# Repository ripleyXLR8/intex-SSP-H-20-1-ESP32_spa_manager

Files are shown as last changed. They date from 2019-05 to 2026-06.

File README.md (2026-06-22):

# WORK IN PROGRESS

# Intex SSP-H-20-1 ESP32 Spa Manager

**WARNING 1 : The circuit in this project uses main voltage (220-240 Volt AC in western Europe). This can be deadly if not handled properly! You can easily hurt yourself as well. Build this circuit at your own risk.**

**WARNING 2 : Never ever ever power this circuit directly without a GFCI outlet (differential circuit breaker). Remember this wircuit will be used in a wet environnement. If you don't understand this, please watch this video https://www.youtube.com/watch?v=SHGo-52wCDc&t=63s and get some electrical knowledge about ground protection.**

**WARNING 3 : This project is still a work in progress, this page is a kind of building log, I haven't finish the board building and installation for the moment. Watch the issues page to see what is working and what is not.**

This project aims to build a replacement for the motherboard of the Intex SSP-20 Spa (it may work with other Intex spa and could be used to build a spa from scratch, but this is not the purpose of this page). My goal was to be able to control the spa remotely and integrate it in my domotic system. The board communicates over the MQTT protocol and publishes Home Assistant MQTT auto-discovery messages, so it integrates out of the box with Home Assistant (and works with any MQTT-based system such as Jeedom https://www.jeedom.com/). The second goal of this project is to improve the reliability of this spa and specificaly to solve a random E95 or E9X error problem. My spa was still under waranty when i started this project so I tried to be as stealth as possible.

## 1) Intex motherboard reverse engineering
Below the annotate picture of the motherboard with my understanding of its working principle. Since the card is labeled, everything is pretty straight forward except the descaler system and the pump system (the upper terminal barrier connector on the board).

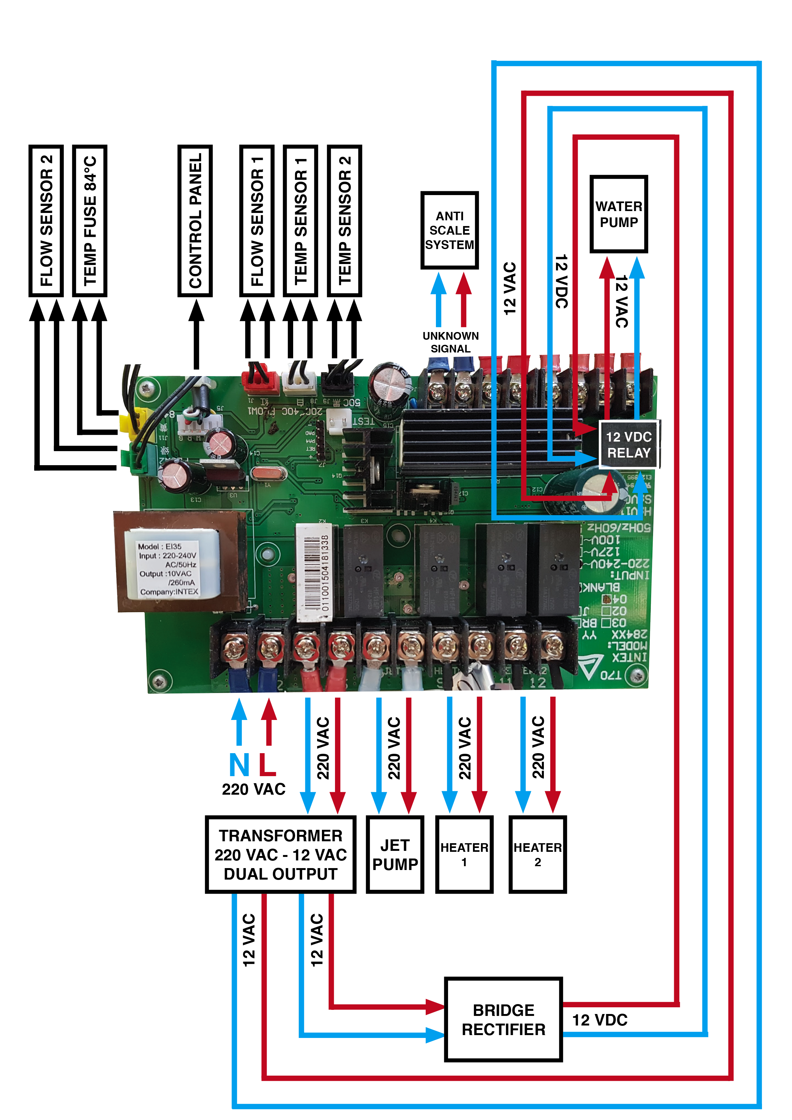
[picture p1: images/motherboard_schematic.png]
Motherboard schematic


### a) Sensors
There are 5 sensors connected to the board, 2 temperature sensors (black and white connectors), 2 flow sensors (red and green connectors) and 1 temperature fuse (yellow connector). They are all connected with a 3 pins JST like connector (it looks like a JST XH 3P but the JST XH 3P doesn't have a lock mecanism).

#### Temperature sensors
Both temperature sensors are negative temperature coefficient (NTC) thermistore, it means that the resistance of the thermistore decreases with an increase in temperature.

- The temperature sensor 1 is installed at the intake of the water pump so it reads the water temperature and it is use to regulate the water temperature from 20°C to 40°C.

- The temperature sensor 2 is installed in the core of  heating elements and its function is to detect overheating over 50°C and shut down the heating if necessary.

Since I'm reading a resistance value and not a temperature, I need to do some calibration (i.e. find a relation between the resistance I'm measuring and the temperature). To measure the real temperature of the water in the spa I connected a DS18B20 thermal sensor in place of the LCD panel. Then I have recorded the temperature of the water and the resistance of both integrated temperature probe of the spa during the heating process of the spa from 18°C to 40°C. The resut once smoothed is the curve presented below. (smoothing is mandatory since the ADC of the ESP32 is pretty noisy...)

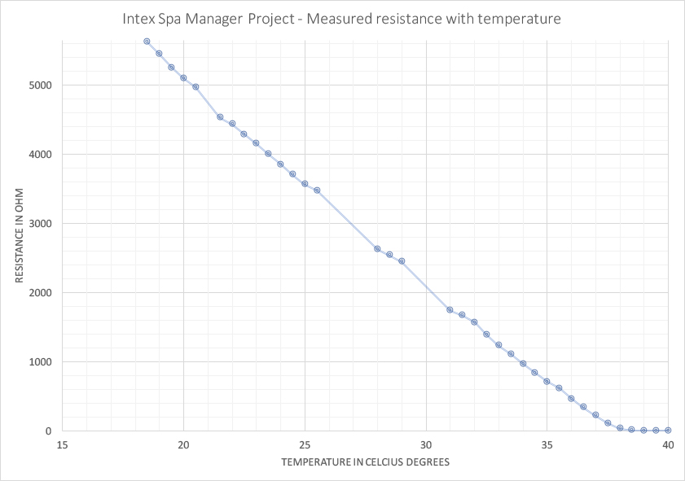
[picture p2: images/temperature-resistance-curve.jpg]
Temperature resistance curve


I first tried to use the Steinhart-Hart equation https://fr.wikipedia.org/wiki/Relation_de_Steinhart-Hart but O did not get good results using this equation, especialy from 34 to 38 degrees.

Since I'm observing that the curve is pretty linear from 18 to 38 degrees, and that the value of the resistance is 0 for 40°C, I tried a linear regression. The result is pretty decent with a R=0,9926.

The equation is T = -276,38*R + 10513

You can also try a logarithmic regression an get the following equation : T = -7750*Ln(R) + 28589 

#### Temperature fuse
One temperature fuse is installed just below heating elements. I cannot test the triggering temperature but it seems that in normal condition the fuse let the current pass and if the temperature goes over 84°C then the fuse burn and the current stop passing and shut down the heating.

#### Flow sensors
Both flow sensors let the current pass only if flow is detected, they ensure that no heating is activated if there is no flow detected in the system.

### b) Power supply, relays and other parts
All the power cable (input and outputs) are connected by a barrier terminal block. We will use the same connector on our board because we don't want to alter the power cable and change their connector.

#### Heating elements
There is two heating element in the spa for a total power of 2000 Watts. They are directly powered by a relay allowing 220VAC to pass trough the heating element.
Please note that in normal condition :
- The water pump is always powered when heating. Any flow interruption signaled by the flow sensor result in an error and the heating stops.
- When you push the heating button the heating doesn't start immediately, the water pump starts and then a couple seconds after the heater 1 is powered then a couple seconds later the heater 2 starts.
- The heater 2 is shut-down if the jet pump is activated.

#### Jet pump
The jet pump is directly powered by a relay allowing 220VAC to pass trough the pump and pumping air into the Spa.

#### Water pump
The water pump is powered by 12VAC but before that a relay allows 220VAC to flow through a dual output 12VAC transformer (see the drawing above). The first output is send to a closed relay and the second output of the transformer goes into a full bridge rectifier producing 12VDC send to activate the relay and let the 12VAC flow into the water pump. It seems that the only goal of this system is to allow the descaling system to start at the same time as the pump (see below the descaling system). On this version on the board we will not implement the descaling system (maybe on the next version) so we will power the pump directly from the output transformer. (connection of A and B wires to C and D wires)

#### Control panel
I will replace the control panel with an external control box connected through the enclosure of the spa with an IP68 SP21-12 connector. (available here : https://www.amazon.com/gp/product/B071R6RSN6/ref=ppx_yo_dt_b_asin_title_o00_s00?ie=UTF8&psc=1)

#### Descaler system
It seems that this spa is equiped by a magnetic descaling system. Here is the wikipedia page on this technology (https://en.wikipedia.org/wiki/Magnetic_water_treatment). I cannot find the type of signal send to this device, it seems that the signal is AC with a modulation of amplitude. I will maybe investigate it later... so this function has not been implemented on the replacement board.

## 2) Designing the replacement board
### a) Working principle
An ESP32 (DevKitc) is the heart of the system. It allows us to connect : 
- 2 temperature sensors on 2 analog inputs,
- 2 flow sensors on 2 digital inputs,
- 1 temperature fuse on 1 digital input,
- 5 buttons on 5 digital input (PUMP, HEATING, JET, +, -),
- 1 LCD display on 2 digital inputs (I2C protocol),
- 4 power relays on 4 digital inputs.

Relays, LCD, temperature sensors, flow sensors, and buttons will not be powered from the 5 Volt pin of the arduino, we will use directly the 5 Volt DC power supply to power them directly.

The integrated wifi chip also allow us to connect to the wifi and the MQTT server to send and receive data.

### b) Electrical drawing
I used Eagle 8.2.2 to design the replacement board, below is the electrical drawing. The eagle files will be available soon.

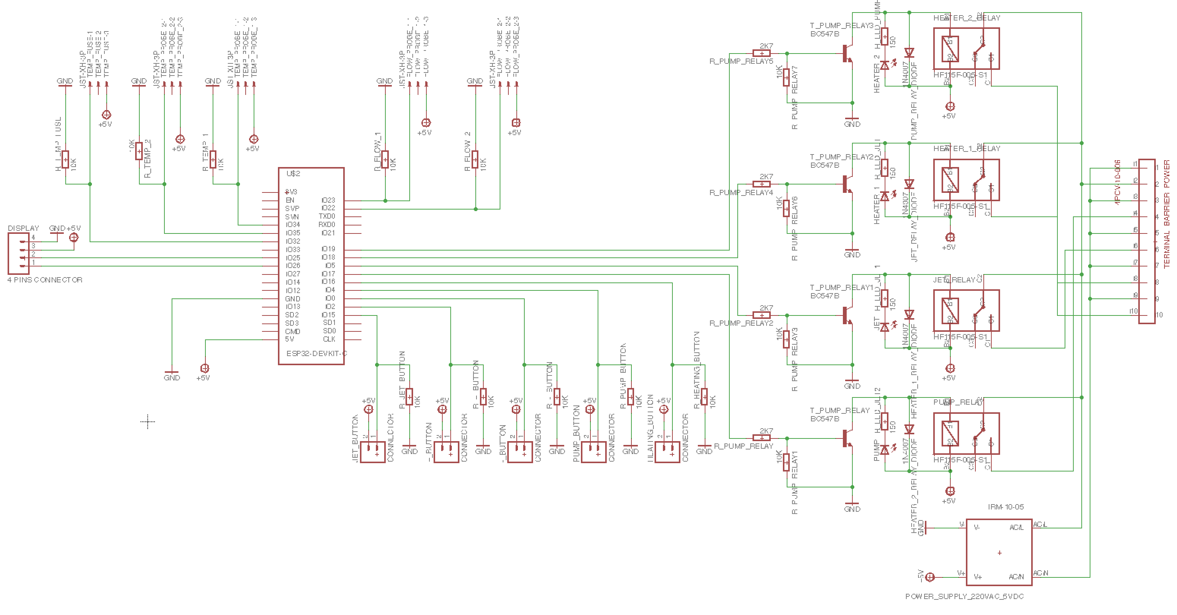
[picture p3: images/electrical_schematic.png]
Electrical schematic


### c) Board schematic
I wanted the board to be easily produce at home by anybody so I choose to use a single side PCB with plated-trhough holes (PTH) components. SMD component will be a also good choice, but I know that occasionnal welder are more at ease with PTH components. The drilling size is 0.8mm, the width of the electrical tracks is 16mil (0.40mm) and the clearance is 10mil (0.25mm), theses parameters allows you to produce the board using the toner transfer method (this method requires very few tools).

Relays are integrated on the board to be integrated more easily in the original enclosure.

The original motherboard dimension are 10.5 cm x 17 cm, mounting hole are 5mm wide and are placed 4.5mm from the edge of the board. The PCB will be mounted using the same mounting screw used by the original motherboard (but I don't think I will be using the center plastic lock).

The power tracks (tracks going to relays) will carry a lot of current. The total power of the Spa announced by Intex is 2200 watts. I have made some measurement on the original board to see how much current is use by each component :

- Heater 1 : 6.70A (Peak at startup) / 3.70A (Cruise) @ 220 Volt AC
- Heater 2 : 7.00A (Peak at startup) / 4.00A (Cruise) @ 220 Volt AC
- Water pump : 0.16A @ 12 Volt AC (This measure include also de descaler) 
- Air pump : 5.50A (Peak at startup) / 3.60A (Cruise) @ 220 Volt AC

As we can see, if everything is running at the same time the spa can draw a total of 11.46A with a peak at startup of 19,36A which is a lot. In the original board there is some rules to avoid the spa to reach this high current drawing :

- Heater 1 and 2 have a 20 seconds startup delay between each other.
- Air pump and heater 2 can't run at the same time.

We will implement the same rules to our board so the maximum current draw will be around 8A with a peak around 11A when starting the heater or the pump. (Which is about what is announced by Intex around 2400 Watts). By dimension the track width for 10A, 2oz/ft copper, an ambiant temperature of 25°C and a maximum temperature elevation of 5 degrees, we find that we need a 2,36 mm (93mil) track width.

### d) Board production
Board schematic has been sent to PCBway a chinese PCB prototyping company. https://www.pcbway.com/. They can even populate your board with the component if you want them to do it.

The list of component with links to buy them is provided below :

## 5) How to configure and install the new control board
### a) Uploading the code and first-boot configuration
Open the lastest `*.ino` file within the Arduino IDE. You no longer need to edit WiFi or MQTT credentials in the code — they are configured at runtime through a captive WiFi portal (WiFiManager) and saved in the ESP32 flash memory.

The feature flags at the top of the sketch are enabled by default and normally don't need to be changed :
`const bool wifi_enable = true;`
`const bool mqtt_enable = true;`
`const bool ota_enable = true;`  // WiFi OTA: lets you upload future updates over the air, without opening the case

Place your ESP32 on a breadboard, select the ESP32 board, set the baudrate to 115200 and upload the code. Once the upload is finished, press the reset button of the board.

On first boot (or whenever it cannot reach a known WiFi network) the board starts a WiFi access point named **`Spa-Intex-Config`**. Connect to it with a phone or computer and a captive portal opens where you set :
- your WiFi network and password,
- the MQTT server address and port (default `1883`),
- the MQTT username and password (leave empty if your broker has no authentication),
- the **OTA password** that protects over-the-air firmware updates.

These settings are stored permanently in the ESP32 flash. To erase the saved WiFi configuration and force the portal to reopen, **hold the BOOT button (GPIO 0)** while resetting the board.

⚠️ **Set the OTA password.** If you leave it empty, anyone on your network can flash arbitrary firmware to a board that switches 2 kW of mains heaters. The board logs a red warning at start-up while the OTA password is unset.

If the board cannot connect to WiFi within the portal timeout (180 s) it falls back to an **offline mode** : the local heating, filtration and jet logic keeps running, but no remote control is available.

### b) Checking the board connection
Open the serial port monitor of the Arduino IDE and set the baudrate to 115200. You should see the start-up sequence and the IP of your board on the WiFi network. Once connected, you can also open a **Telnet** session to that IP (port 23) to watch the live dashboard remotely — it prints the temperature, target, thermostat/filtration/jet/heater states and the anti-short-cycle timer every few seconds.

If you have any error message during the start-up you should check your configuration in the WiFi portal.

### c) Controlling the spa over MQTT
The board uses MQTT only (the previous HTTP/REST interface has been removed). It publishes its full state as a JSON payload to the **`spa_intex/info`** topic, for example :

`{"flow_1":true,"flow_2":true,"temp_1":21.3,"temp_2":21.8,"target":35.0,"heartbeat":65065,"thermostat":false,"filtration":false,"heater":false,"jet":true,"fuse":true,"bypass_flow":false,"bypass_fuse":false}`

In that payload `fuse:true` means the thermal fuse reads intact (safe to heat) and `flow_1/flow_2:true` mean water flow is detected.

Command topics (publish `1` or `0`, or a number for the target) :
- `spa_intex/target` -> set the target temperature (°C, capped at 39 °C).
- `spa_intex/thermostat` -> enable/disable the temperature regulation (enabling it also turns filtration on). Accepts `1`/`0` or `heat`/`off`.
- `spa_intex/filtration` -> enable/disable the filtration (water pump).
- `spa_intex/jet` -> enable/disable the jet (air pump / bubbles).
- `spa_intex/reset` -> publish `1` to reboot the board after a 10 s delay.
- `spa_intex/bypass_flow` -> override the water-flow interlock (see safety section below).
- `spa_intex/bypass_fuse` -> override the thermal-fuse interlock (see safety section below).

On every successful MQTT connection the board also publishes **Home Assistant MQTT auto-discovery** messages (under the `homeassistant/...` topics), so the device appears automatically as "Spa Intex" in Home Assistant — no manual entity configuration required. The thermostat is exposed as a single **`climate`** entity (current temperature, target slider, off/heat mode and a heating/idle indicator); the filtration and jet are switches, and the two interlock overrides are switches in the *Configuration* section. (The thermostat + setpoint were previously two separate switch/number entities — these are now removed in favour of the climate card.)

### d) Safety interlocks and current limiting
The heating logic enforces several hardware-protection rules. The heater stays off unless **all** of these hold:
- the thermostat is enabled and the water is below target (with a ±1 °C hysteresis band),
- **water flow is detected** on both flow sensors (`flow_1` and `flow_2`),
- the **thermal fuse reads intact** (`fuse`),
- the water temperature is below the 39 °C safety ceiling,
- the 15-minute anti-short-cycle timer allows the change (bypassed once on the first cycle).

To limit the inrush current (the original board draws up to ~19 A peak with everything starting at once), the firmware reproduces the factory rules: **heater 2 starts only ~20 s after heater 1**, and **heater 2 never runs at the same time as the jet/air pump** (turning the jet on temporarily drops heater 2). The live dashboard (serial / Telnet) shows which interlock is currently blocking the heater.

**Input polarity must match your board.** The active levels are defined at the top of the sketch:
`#define FLOW_ACTIVE_LEVEL HIGH` (level read when water flows) and `#define FUSE_OK_LEVEL HIGH` (level read when the fuse is intact). They default to *high = active*; if your wiring is inverted, flip these two `#define`s, otherwise the interlocks will read backwards. A disconnected flow or fuse input is treated as "no flow / fuse tripped" and **blocks heating** (fail-safe) — so the thermal-fuse (yellow) and flow connectors must be wired and working for the spa to heat.

#### Bypassing a broken sensor
If a flow sensor or the thermal fuse is faulty and you knowingly want to keep heating until you can replace it, two MQTT overrides let you bypass the interlock without touching the code:
- `spa_intex/bypass_flow` -> publish `1` to ignore the water-flow check, `0` to restore it.
- `spa_intex/bypass_fuse` -> publish `1` to ignore the thermal-fuse check, `0` to restore it.

Both are exposed as switches in the **Configuration** section of the Home Assistant device ("Spa Bypass Debit" / "Spa Bypass Fusible"), reported in the `info` payload (`bypass_flow` / `bypass_fuse`), and shown on the serial/Telnet dashboard (`Securites : Fusible [ACTIVE/CONTOURNEE] | Debit [...]`) with a red warning when engaged.

⚠️ **A bypass resets to OFF on every reboot/power-cycle** — it is deliberately not persisted, so cycling power always restores full safety. Bypassing the thermal fuse removes overheat protection; the only remaining backstop is the 39 °C software ceiling on the regulation sensor. Use these overrides only as a temporary measure and never leave the spa unattended while a bypass is active.

### e) Removing the old control board
First, it is very important to DISCONNECT THE POWER CABLE of the Spa. Remove the four screws securing the spa cover and remove it. Then locate the cover of the control board, remove all the screws and remove the cover. On the control board remove all cable from the lower and upper terminal, from the sensors and from the control panel, then remove the four screws securing the board and remove it.

### f) Installation of the new control board
Remove the central plastic pin in order to install the new board into the enclosure and then install the new board using the 4 screws from the old board. Then connect the old cables on the new board. Here is a quick connection guide based on the color of my board (double check it with you board before powering up the spa) :

- Red connector -> Flow 1 connector
- Green connector -> Flow 2 connector
- White connector ->  Temperature 2 connector
- Black connector ->  Temperature 1 connector
- Yellow connector -> DO NOT CONNECT (it doesn't work currently)
- Connector 1 -> N terminal
- Connector 2 -> L terminal
- Connector 5 -> N of the pump terminal
- Connector 6 -> L of the pump terminal
- Connector 7 -> N of the jet terminal
- Connector 8 -> L of the jet terminal
- Connector 9 -> N of the heater 1 terminal
- Connector 10 -> L of the heater 1 terminal
- Connector 11 -> N of the heater 2 terminal
- Connector 12 -> L of the heater 2 terminal

Then you have to connect together some wires from the upper terminal and isolate all non connected wires before powering up the spa.
- Cable A must be connected with cable C
- Cable B must be connected with cable D

You should get something like that :
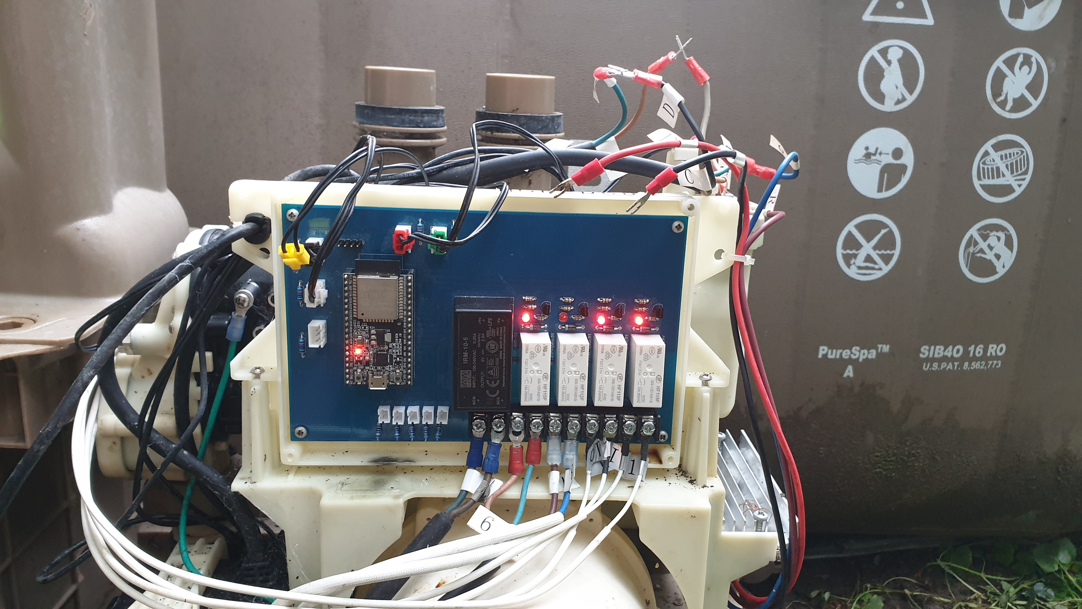
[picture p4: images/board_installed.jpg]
Board installed


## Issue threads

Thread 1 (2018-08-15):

Project Update

olivercastle, 2018-08-15:
Hey Richard,

Great project you have started here. I'm also looking to do something similar to my Intex spa. Final product would ideally be able to control the spa remotely maybe using ifttt or something of the like.

Are you still working on this? Have you made any progress since your last commit?

Thanks.

ripleyXLR8, 2018-08-16:
Hello Oliver,

Unfortunately I had two major problems in this project. My computer has
been stolen with all the code i had written and the first PCB i ordered
online had some major design flaw. So the project has been kinda stopped.

I have designed a new version of the PCB but it must be checked before
sending it to production. I can send it to you soon.

Best regards

Richard

Le mer. 15 août 2018 à 06:31, Oliver Castle <notifications@github.com> a
écrit :

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

olivercastle, 2018-08-20:
Hi Richard,

Sorry to hear about your computer.

Yes would be really interested in seeing what you come up with.

Oliver

ripleyXLR8, 2018-08-22:
This is the last version of the board I designed. (eagle files)

There is still some things to check :

1) I'm using a lot of input from the ESP32, i did not check if they can be
used simultaneously (i had some surprise on previous project with the ESP
32)
2) Value for component must be checked.
3) I did not reverse the descaling system.

Thank you for your mail.

Actually you gave me some strenght to get back to work on this project.

I will try to finish  the board before the end of august.

Best regards

Richard

2018-08-20 19:34 GMT-04:00 Oliver Castle <notifications@github.com>:

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

--
*Richard Perez*
*Tel : 06 25 68 70 54*

*Importateur Exclusif France*

*  & *

Listwa, 2018-09-18:
Hi,
I am following. Would like to also remotely control the Intex Spa.  I use my Spa at a vacation home on weekends and lower  the temp when i leave.  I would love to simply be able to raise the temp to 104,  a day before i arrive.  I was looking for a way just to tap a raspberry Pi or an arduino into the control panel to control the temp.  Any  ideas are welcome.

Regards
Les

tinwhisker, 2019-01-31:
Hi guys,

I have a pet-project for a similar goal to Richards, but reading the bad news, I thought I'd reach out if anyone was interested? Even if it's a stop-gap.

Personally it was on hiatus for a while, but decided to pick it back up. But being lazy, I thought I'd check GitHub first and found this project.

It takes a different approach, using the display lines for state/control, as I wanted as minimal modification as possible. (Like Richard, mine was in warranty when I started).

Four wires - power, data and clock. An ESP8266 sits in parallel to the display board.
Just revisiting write-back stability, but I'll throw it up on GitHub if anyone wants a peek.

I'm half tempted to move it to where the main board lives to gain access to a reset pin, so I can clear errors too.

Listwa, 2019-01-31:
Yes, please share. Pictures also of where  and how you connected to the
display.

Would love to remotely adjust the Spa,

Les

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

olivercastle, 2019-02-01:
@tinwhisker Yes, if we can combine efforts that would be awesome too.
I also had the thought of an Arduino running in tandem with the existing board so we're not removing the current functionality only extending it.

@ripleyXLR8 Do you have any thoughts on that?

Personally, my main goal is to be able to turn my system on/off / adjust temperatures during certain times of the day (low electrical cost times for example).

Thanks!

Listwa, 2019-02-01:
Hi Oliver,

An Arduino or Raspberry Pi would be the way to go and yes running in
tandem.  One of the problems I am dealing with is that after a power outage
( I get many), the unit has to be manually turned back on and temp
readjusted.  Its located at a Vacation home, so I keep  the temp low and
raise it when I get there and have to wait  and wait for it to come to
temp.    I have played with a Raspberry pi with a water proof temp sensor
to tell me what the temp is remotely, but that is as far as my technical
capabilities .  Never bothered to take the control unit apart and hack into
it.

Les

On Fri, Feb 1, 2019 at 9:13 AM Oliver Castle <notifications@github.com>
wrote:

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

tinwhisker, 2019-02-01:
The Pi might be able to do it if you can have decent control over the SPI lines.
I don't think it's interrupts would be fast enough.
You could definitely use a cheap arduino, (especially a Leonardo or Teensy) to do the grunt work, though the ESP keeps cost to a minimum.

The ESP on my first go wasn't so happy with SPI abuse, but may try again if I can confirm it's SPI interrupt is separate. Bit-banging is quite CPU intensive, but doesn't need realtime reading - even every 500ms is overkill, just syncing to the data line adds time.

Write-back is clever, but fiddly as, from what I remember, the spa clocks a bit through the two 595's, checking the data line for state change (where a button is pulling it up/down), then clocks again.
Get the write-back wrong and the panel locks out.

I'll try get a good snapshot of the data line again tomorrow if I can't find my original.
Tonight I'm using the tub, so not allowed to tinker!

tinwhisker, 2019-02-01:
Does anyone have a picture of the back of the main board? I can only find component side images.

Listwa, 2019-02-09:
Hi,

I am going to go for now in a different direction.  As I would like to keep the temp down for weeks at a time, since I only occasionally use the Spa , but rapidly warm it up and not wait 24 hours.  I am looking to pair a Camplux 5L 1.32 GPM Outdoor Portable Propane Tankless Water Heater with a 12V circulating pump. Looks like it can heat the Intex up 20 degrees per hour.  Just got a deal for a refurbished Camplux direct form the manufacture for under $50.  To keep things simple i am going to pair it with a Sonoff TH10 and  ds18b20 temp sensor  .   With out fussing with programming, using the ewelink app and stringify, allow me to set temperature and cycle  on and off as need.  I have been playing with the TH10/DS18b20 and ewelink app for sometime to monitor a 2nd home and it works perfectly and the pair can be had for $11.  So i think I got me a solution.

tinwhisker, 2019-02-09:
Sounds a bargain @listwa but how does the running cost compare?

I've looked into using diesel heaters, but breaking even was just worth waiting, given I have night rates on my electricity, and the ESP project (I haven't forgotten) to give it some autonomy.
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
pebsi, 2019-11-26:
Hi, Is this still being worked on? I would be very keen to convert my spa over to have wifi control and readouts from it.

jperquin, 2020-02-09:
> Hi, Is this still being worked on? I would be very keen to convert my spa over to have wifi control and readouts from it.

+1 here too.

Have the octagonal / 6 person model Intex 28456 with descaling and salt-water chlorinator. I'd prefer a piggy back system that mimics button presses and reads the LED display on the original control panel.

All of my wifi home automations run on ESP Home with Home Assistant, so straight integration into that eco-system would be even better..

Just my wish list and willing to pitch in on the yaml programming logic side but not experienced with board / electronics design..

nervalo88, 2020-02-11:
Hello,
Thanks to the insights of this project, I've had another aproach based on tweaking existing PCBs.

Check this out : https://github.com/nervalo88/ESP8266_INTEX_SPA

Listwa, 2020-04-10:
Nervalo88.  thats exactly what i am trying to do now!!!  Do you think that 3.3V or 5V can be pulled directly from the C23403 PC card ( the one with the switches) rather then having to run a wire to the motor card?  There is clearly voltage to that board already. Also do you think that the on/off state could be monitored by sampling the  Power and Heater LED when it goes high?  My challange is I have the C28403 board with me and the rest is at another house, so all I can work on is that board untill I can retireve the rest of the Spa.  There is def votage to the board just dont know if its enough to power ESP8266. Thanks
Les

nervalo88, 2020-04-10:
Hello,
Yes, this is probably doable as the 5v is available. I choosed to be in the "base" to get enough space as I use cheap but space consuming modules. But your challenge will be to grab the statuses (heating? Power?) as those are muxed through a 74hc595, wich is also used by the microcontroller in the base to know switches presses... Reading signals on this c28403 might perturbate the operation. Everything is possible, but I was unsuccessful to reverse engineer the bus between c28403 and the base. I even used a separate temperature sensor...
Hope this helps!

Listwa, 2020-04-10:
Hi ,

I was thinking that the status of the heating and the on/off can be read
off the base of the  LED , the simple LEDS that are simply on or off.  So
no need to to decode the numeric REDs. I am just talking about the round
round LED indicators.

Les

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

FMonGH, 2020-08-09:
Hi guys
Was following Richards project for a while but then got side tracked.  I've since started automating my home and started playing with Home Assistant and ESP8266 integrations.
Has anyone made some more progress with this project?  Would be keen to look at it again and to integrate it with Home Assistant as it has the ESPHome add on that works quite well.

Francois

pebsi, 2020-08-09:
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

Hi, I followed this for a while and the found someone on youtube who had nade a board for wifi control. I ended up buying his board rather than coding it myself.

https://youtu.be/Uu1ymWx3O58

jperquin, 2020-08-09:
I have been in touch with the maker of that youtube video as well and apparently he sells the source code for an extra fee. I am tempted to do that and see if it can be adapted to ESPHome / HA..

ashmodai6, 2020-08-09:
https://github.com/YorffoeG/diyscip/

Go and check this project
All you need

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

FMonGH, 2020-08-09:
Brilliant!  Thanks guys, I'll check it out.  Love this community

UlrichMai, 2020-08-10:
> https://github.com/YorffoeG/diyscip/ Go and check this project All you need

If you want to have less hardware work, then check out this:
https://github.com/UlrichMai/diyscip/blob/support-saltwaterspa/README.md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
You only need a D1 mini, 2 resistors and diode. It is working for me and @red-gee.
Unfortunately my contribution to this project was was not accepted.

FMonGH, 2020-08-10:
Thanks Ulrich
Appreciate the feedback!

Cheers
Francois

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

galaxy4public, 2022-06-01:
Has anybody looked at the latest PureSpa detachable controller that can connect to WiFi by itself (and is powered by ESP out of the box)?  I am tempted to flash it with Tasmota and create a template for the my Intex 28452 PureSpa.  I am just wondering whether anybody else is working on something similar.

galaxy4public, 2022-06-01:
I also found a repair guide with the description of the PCB - https://intexfaq.ch/wp-content/uploads/2021/02/2021-SSN-Combo-Spa-28462-Control-Base-Repair-Guide.pdf (the guide covers both the pre-2021 and past-2021 boards).

galaxy4public, 2022-06-01:
According to the repair guide, the heaters are connected slightly different from what @ripleyXLR8 found during their analysis.

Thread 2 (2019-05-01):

Temperature reading is 0 if the temperature fuse is connected

ripleyXLR8, 2019-05-01:
When connecting the temperature fuse, the reading of the temperature is 0. I'm investigating the problem, we will probably need to change the pin for the temperature fuse in the next release.

Current workaround : disconnect the temperature fuse.

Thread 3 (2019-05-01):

Reset button needs to be press after powering for the ESP32 to boot.

ripleyXLR8, 2019-05-01:
If the ESP32 is connected to the board, then when you connect the power supply you need to press the reset button on the ESP32 to make the ESP32 boot.

This is probably link to the one of the 4 GPIO of the relay being pulled down during the boot. I need to investigate which GPIO is producing this behavior and change it in the next release of the board.

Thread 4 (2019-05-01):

Defaults coefficients for the Steinhart-Hart equation and not accurate for temperature reading.

ripleyXLR8, 2019-05-01:
The value provided by the read temperature function using the Steinhart-Hart equation with default coefficients are not accurate.

I need to make a calibration to determine correct coefficients for Intex probes.

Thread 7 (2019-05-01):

Button for Spa control are not reliable

ripleyXLR8, 2019-05-01:
Needs to investigate the issue

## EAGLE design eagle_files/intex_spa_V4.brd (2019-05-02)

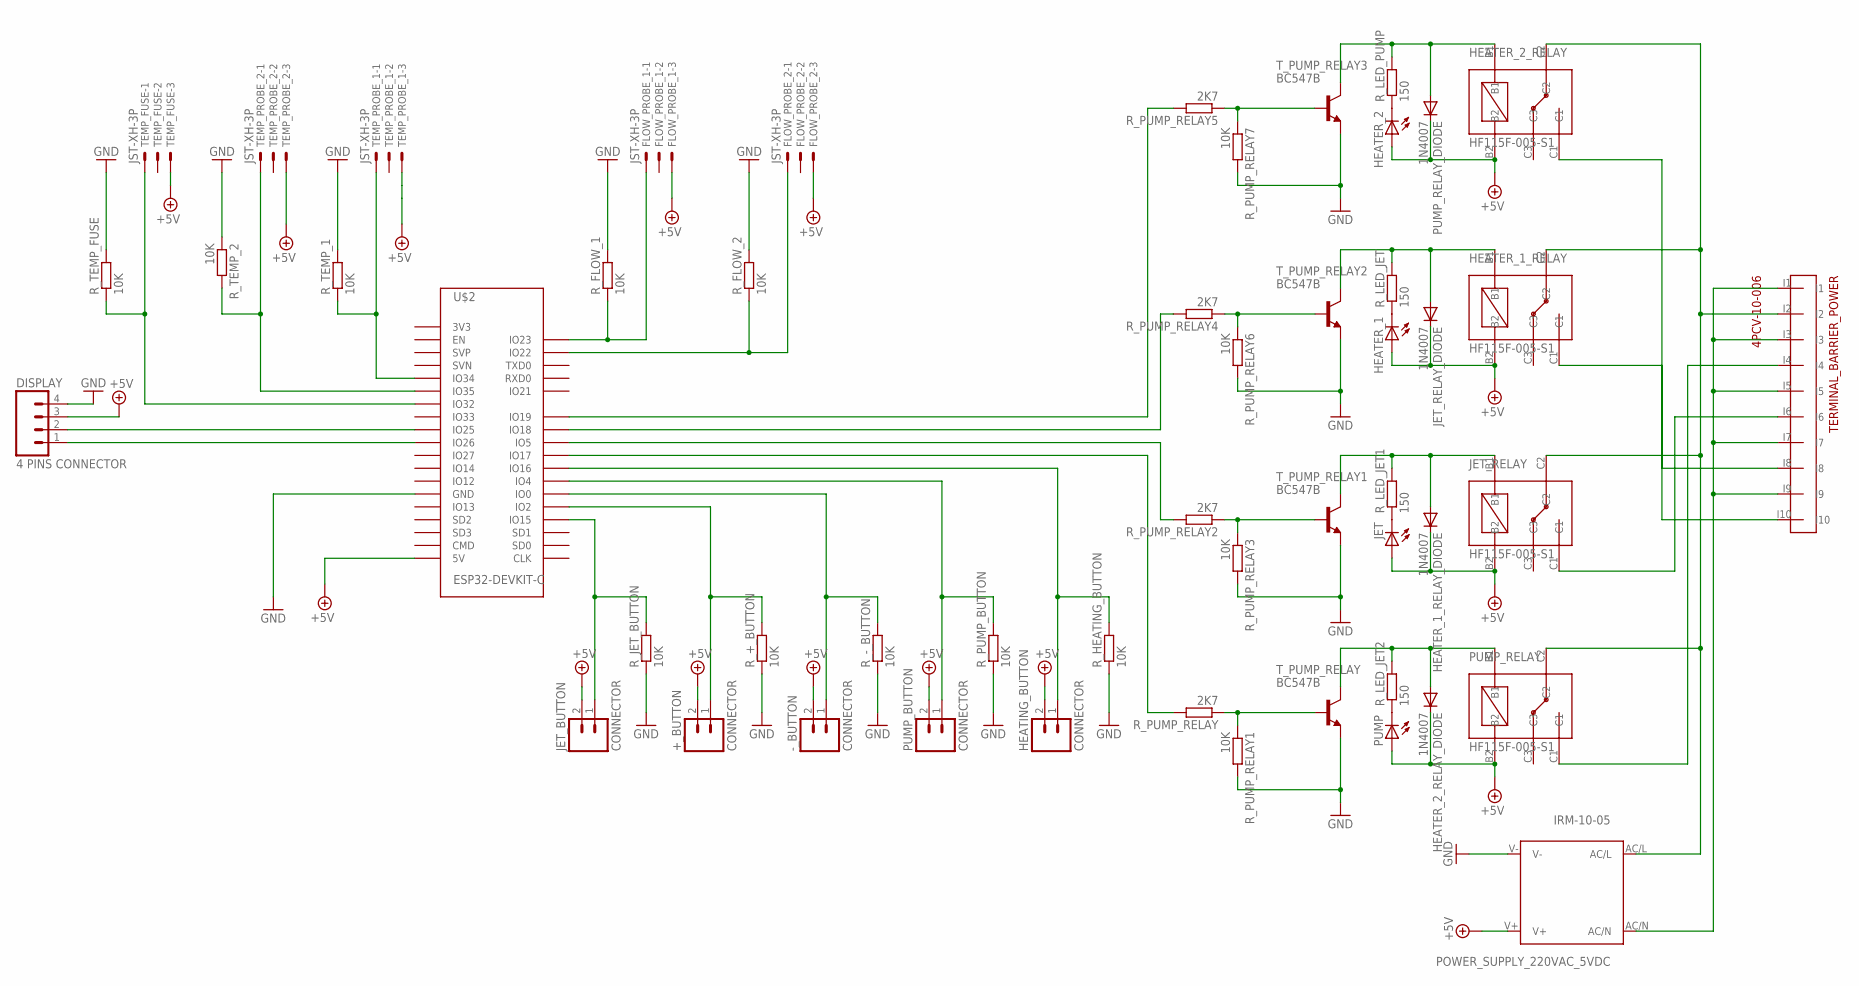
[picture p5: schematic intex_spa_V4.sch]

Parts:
+_BUTTON: CONNECTOR; JST-2-PTH-VERT
-_BUTTON: CONNECTOR; JST-2-PTH-VERT
DISPLAY: 4 PINS CONNECTOR; 1X04
FLOW_PROBE_1, FLOW_PROBE_2: JST-XH-3P; JST-XH-03-PACKAGE-LONG-PAD
HEATER_1, HEATER_2: LED3MM
HEATER_1_RELAY, HEATER_2_RELAY: HF115F-005-S1
HEATER_1_RELAY_DIODE, HEATER_2_RELAY_DIODE: 1N4007; DO41-10
HEATING_BUTTON: CONNECTOR; JST-2-PTH-VERT
JET: LED3MM
JET_BUTTON: CONNECTOR; JST-2-PTH-VERT
JET_RELAY: HF115F-005-S1
JET_RELAY_DIODE: 1N4007; DO41-10
POWER_SUPPLY_220VAC_5VDC: IRM-10-05; IRM_05/10
PUMP: LED3MM
PUMP_BUTTON: CONNECTOR; JST-2-PTH-VERT
PUMP_RELAY: HF115F-005-S1
PUMP_RELAY_DIODE: 1N4007; DO41-10
R_+_BUTTON: 10K; 0204/5
R_-_BUTTON: 10K; 0204/5
R_FLOW_1, R_FLOW_2: 10K; 0207/10
R_HEATING_BUTTON: 10K; 0204/5
R_JET_BUTTON: 10K; 0204/5
R_LED_JET, R_LED_JET1, R_LED_JET2: 150; 0204/5
R_LED_PUMP: 150; 0204/5
R_PUMP_BUTTON: 10K; 0204/5
R_PUMP_RELAY, R_PUMP_RELAY2, R_PUMP_RELAY4, R_PUMP_RELAY5: 2K7; 0204/5
R_PUMP_RELAY1, R_PUMP_RELAY3, R_PUMP_RELAY6, R_PUMP_RELAY7: 10K; 0204/5
R_TEMP_1, R_TEMP_2: 10K; 0207/10
R_TEMP_FUSE: 10K; 0207/10
TEMP_FUSE: JST-XH-3P; JST-XH-03-PACKAGE-LONG-PAD
TEMP_PROBE_1, TEMP_PROBE_2: JST-XH-3P; JST-XH-03-PACKAGE-LONG-PAD
TERMINAL_BARRIER_POWER: 4PCV-10-006
T_PUMP_RELAY, T_PUMP_RELAY1, T_PUMP_RELAY2, T_PUMP_RELAY3: BC547B; TO92
U$2: ESP32-DEVKIT-C

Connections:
+5V: +_BUTTON.2, -_BUTTON.2, DISPLAY.3, FLOW_PROBE_1.3, FLOW_PROBE_2.3, HEATER_1.A, HEATER_1_RELAY.B2, HEATER_1_RELAY_DIODE.C, HEATER_2.A, HEATER_2_RELAY.B2, HEATER_2_RELAY_DIODE.C, HEATING_BUTTON.2, JET.A, JET_BUTTON.2, JET_RELAY.B2, JET_RELAY_DIODE.C, POWER_SUPPLY_220VAC_5VDC.V+, PUMP.A, PUMP_BUTTON.2, PUMP_RELAY.B2, PUMP_RELAY_DIODE.C, TEMP_FUSE.3, TEMP_PROBE_1.3, TEMP_PROBE_2.3, U$2.5V
GND: DISPLAY.4, POWER_SUPPLY_220VAC_5VDC.V-, R_+_BUTTON.1, R_-_BUTTON.1, R_FLOW_1.2, R_FLOW_2.2, R_HEATING_BUTTON.1, R_JET_BUTTON.1, R_PUMP_BUTTON.1, R_PUMP_RELAY1.2, R_PUMP_RELAY3.2, R_PUMP_RELAY6.2, R_PUMP_RELAY7.2, R_TEMP_1.2, R_TEMP_2.1, R_TEMP_FUSE.2, T_PUMP_RELAY.1 (E), T_PUMP_RELAY1.1 (E), T_PUMP_RELAY2.1 (E), T_PUMP_RELAY3.1 (E), U$2.GND, U$2.GND2 (GND), U$2.GND3 (GND)
LEAD: HEATER_1_RELAY.C2, HEATER_2_RELAY.C2, JET_RELAY.C2, POWER_SUPPLY_220VAC_5VDC.AC/L, PUMP_RELAY.C2, TERMINAL_BARRIER_POWER.I2
LEAD_HEATER_1: HEATER_1_RELAY.C1, TERMINAL_BARRIER_POWER.I8
LEAD_HEATER_2: HEATER_2_RELAY.C1, TERMINAL_BARRIER_POWER.I10
LEAD_JET: JET_RELAY.C1, TERMINAL_BARRIER_POWER.I6
LEAD_PUMP: PUMP_RELAY.C1, TERMINAL_BARRIER_POWER.I4
unnamed: R_PUMP_RELAY.2, U$2.IO17
unnamed: R_TEMP_2.2, TEMP_PROBE_2.1, U$2.IO35
unnamed: FLOW_PROBE_2.1, R_FLOW_2.1, U$2.IO22
unnamed: R_PUMP_RELAY5.2, U$2.IO19
unnamed: R_PUMP_RELAY4.2, U$2.IO18
unnamed: R_PUMP_RELAY2.2, U$2.IO5
unnamed: HEATER_2.K (C), R_LED_PUMP.1
unnamed: R_TEMP_FUSE.1, TEMP_FUSE.1, U$2.IO32
unnamed: FLOW_PROBE_1.1, R_FLOW_1.1, U$2.IO23
unnamed: DISPLAY.1, U$2.IO26
unnamed: DISPLAY.2, U$2.IO25
unnamed: HEATING_BUTTON.1, R_HEATING_BUTTON.2, U$2.IO16
unnamed: -_BUTTON.1, R_-_BUTTON.2, U$2.IO0
unnamed: PUMP_BUTTON.1, R_PUMP_BUTTON.2, U$2.IO4
unnamed: +_BUTTON.1, R_+_BUTTON.2, U$2.IO2
unnamed: JET_BUTTON.1, R_JET_BUTTON.2, U$2.IO15
unnamed: JET.K (C), R_LED_JET1.1
unnamed: HEATER_1_RELAY_DIODE.A, JET_RELAY.B1, R_LED_JET1.2, T_PUMP_RELAY1.3 (C)
unnamed: HEATER_1.K (C), R_LED_JET.1
unnamed: PUMP.K (C), R_LED_JET2.1
unnamed: HEATER_2_RELAY_DIODE.A, PUMP_RELAY.B1, R_LED_JET2.2, T_PUMP_RELAY.3 (C)
unnamed: R_TEMP_1.1, TEMP_PROBE_1.1, U$2.IO34
unnamed: R_PUMP_RELAY.1, R_PUMP_RELAY1.1, T_PUMP_RELAY.2 (B)
unnamed: HEATER_1_RELAY.B1, JET_RELAY_DIODE.A, R_LED_JET.2, T_PUMP_RELAY2.3 (C)
unnamed: HEATER_2_RELAY.B1, PUMP_RELAY_DIODE.A, R_LED_PUMP.2, T_PUMP_RELAY3.3 (C)
unnamed: R_PUMP_RELAY2.1, R_PUMP_RELAY3.1, T_PUMP_RELAY1.2 (B)
unnamed: R_PUMP_RELAY4.1, R_PUMP_RELAY6.1, T_PUMP_RELAY2.2 (B)
unnamed: R_PUMP_RELAY5.1, R_PUMP_RELAY7.1, T_PUMP_RELAY3.2 (B)
NEUTRAL: POWER_SUPPLY_220VAC_5VDC.AC/N, TERMINAL_BARRIER_POWER.I1, TERMINAL_BARRIER_POWER.I3, TERMINAL_BARRIER_POWER.I5, TERMINAL_BARRIER_POWER.I7, TERMINAL_BARRIER_POWER.I9

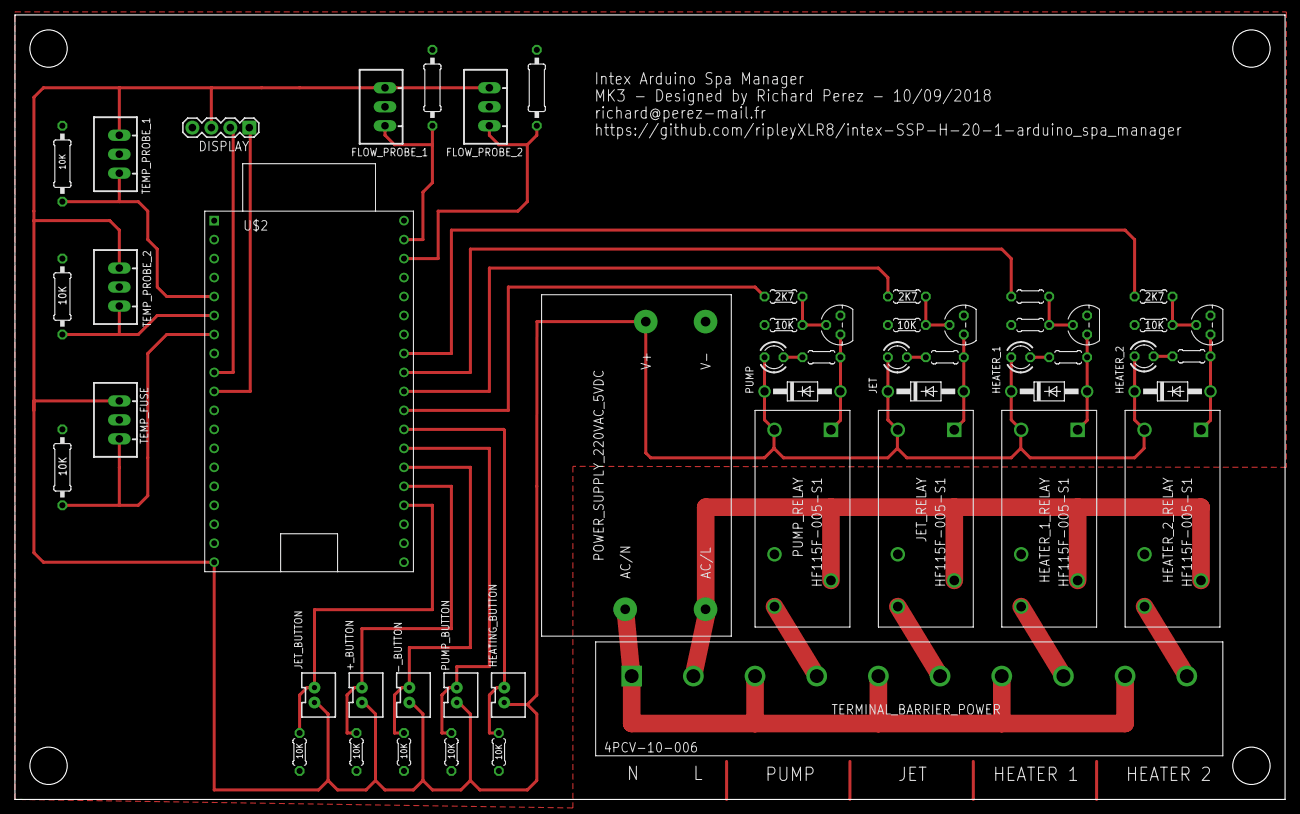
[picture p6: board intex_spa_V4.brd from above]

Board: 2 copper layers, 170.0 x 105.0 mm, 52 parts (0 on the bottom side), 36 nets.

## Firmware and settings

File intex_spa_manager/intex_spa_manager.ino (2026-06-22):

#include <WiFi.h>
#include <PubSubClient.h>
#include <ArduinoOTA.h>
#include <Arduino_JSON.h>
#include <esp_task_wdt.h> // Native library for the Watchdog
#include <WiFiManager.h>  // Library for the WiFi captive portal
#include <Preferences.h>  // Library to persist MQTT settings in flash

// Watchdog configuration
#define WDT_TIMEOUT 8 // Grace period in seconds before a forced reboot

// Feature configuration
const bool wifi_enable = true;
const bool mqtt_enable = true;
const bool ota_enable = true;

// --- ANSI COLORS FOR THE TERMINAL ---
#define C_RESET   "\033[0m"
#define C_RED     "\033[1;31m"
#define C_GREEN   "\033[1;32m"
#define C_YELLOW  "\033[1;33m"
#define C_CYAN    "\033[1;36m"
#define C_MAGENTA "\033[1;35m"

// Timers and intervals
unsigned long previousHeartbeat = 0;
unsigned long previousSensorRead = 0;
unsigned long heartbeat;
const unsigned long sensor_read_interval = 500;
const unsigned long mqtt_update_interval = 20000;

// Heating cycle parameters (anti-short-cycle)
unsigned long lastHeatingStateChange = 0;
const unsigned long minHeatingCycle = 15 * 60 * 1000; // 15 minutes

// Inrush current limiting: startup stagger between the two heating elements
unsigned long heater1OnTime = 0;
const unsigned long heaterStageDelay = 20000; // 20s between heater 1 and 2 (per the original board)
bool isFirstCycle = true;

// Variables for the non-blocking reset
bool resetRequested = false;
unsigned long resetTimer = 0;
const unsigned long resetDelay = 10000;

// ==========================================
// DYNAMIC CONFIGURATION (WIFIMANAGER)
// ==========================================
Preferences preferences;

char mqttServer[40] = "";
char mqttPortStr[6] = "1883";
int  mqttPort = 1883;
char mqttUser[32] = "";
char mqttPass[32] = "";
char otaPass[32] = ""; // password for OTA updates (empty = OTA unprotected)

bool shouldSaveConfig = false;

void saveConfigCallback() {
  Serial.println("Configuration change detected. Save requested.");
  shouldSaveConfig = true;
}

void loadConfig() {
  preferences.begin("spa_config", false);
  String s_server = preferences.getString("mqtt_server", "");
  String s_port   = preferences.getString("mqtt_port", "1883");
  String s_user   = preferences.getString("mqtt_user", "");
  String s_pass   = preferences.getString("mqtt_pass", "");
  String s_ota    = preferences.getString("ota_pass", "");

  strcpy(mqttServer, s_server.c_str());
  strcpy(mqttPortStr, s_port.c_str());
  strcpy(mqttUser, s_user.c_str());
  strcpy(mqttPass, s_pass.c_str());
  strcpy(otaPass, s_ota.c_str());

  mqttPort = atoi(mqttPortStr);
  preferences.end();
}

void saveConfig() {
  preferences.begin("spa_config", false);
  preferences.putString("mqtt_server", mqttServer);
  preferences.putString("mqtt_port", mqttPortStr);
  preferences.putString("mqtt_user", mqttUser);
  preferences.putString("mqtt_pass", mqttPass);
  preferences.putString("ota_pass", otaPass);
  preferences.end();
  shouldSaveConfig = false;
}

// ==========================================
// STATE VARIABLES
// ==========================================
bool request_mqtt_update = false;

// Telnet server for OTA debug
WiFiServer telnetServer(23);
WiFiClient telnetClient;

// MQTT topic list
const char* mqttTopicJet = "spa_intex/jet";
const char* mqttTopicFiltration = "spa_intex/filtration";
const char* mqttTopicTarget = "spa_intex/target";
const char* mqttTopicTempRegulation = "spa_intex/thermostat";
const char* mqttTopicInfo = "spa_intex/info";
const char* mqttTopicReset = "spa_intex/reset";
const char* mqttTopicError = "spa_intex/error";
const char* mqttTopicBypassFlow = "spa_intex/bypass_flow";
const char* mqttTopicBypassFuse = "spa_intex/bypass_fuse";

// Pin configuration
#define HEATER_1_PIN 18
#define HEATER_2_PIN 19
#define JET_PIN 5
#define PUMP_PIN 17
#define FLOW_1_PIN 23
#define FLOW_2_PIN 22
#define TEMP_1_PIN 34
#define TEMP_2_PIN 35
#define TEMP_FUSE_PIN 32

// Logic level of the safety inputs (verify against the board wiring)
#define FLOW_ACTIVE_LEVEL HIGH   // level read when water flow is present
#define FUSE_OK_LEVEL HIGH       // level read when the thermal fuse is intact
#define SERIESRESISTOR_TEMP_1 9980
#define SERIESRESISTOR_TEMP_2 9980

const int num_samples = 20;
const float smoothing_factor = 0.2;
bool first_reading = true;

WiFiClient espClient;
PubSubClient MQTTclient(espClient);

float target_temp = 35.0;
float current_temp = 0.0;
float temp_1 = 0.0;
float temp_2 = 0.0;
bool flow_1 = false;
bool flow_2 = false;
bool fuse = false;
bool offline_mode = false;
bool filtration_enabled = false;
bool jet_enabled = false;
bool temp_regulation_enabled = false;
bool heating_enabled = false;
bool bypass_flow = false; // override of the "water flow" interlock (reset to 0 on boot)
bool bypass_fuse = false; // override of the "thermal fuse" interlock (reset to 0 on boot)

float hysterisys = 1.0;
int max_temp = 39;

// ==========================================
// OTA DEBUG FUNCTIONS
// ==========================================
template <typename T>
void debugPrint(T msg) {
  Serial.print(msg);
  if (telnetClient && telnetClient.connected()) {
    telnetClient.print(msg);
  }
}

template <typename T>
void debugPrintln(T msg) {
  Serial.println(msg);
  if (telnetClient && telnetClient.connected()) {
    telnetClient.println(msg);
  }
}

void debugPrintln() {
  Serial.println();
  if (telnetClient && telnetClient.connected()) {
    telnetClient.println();
  }
}

void handleTelnet() {
  if (telnetServer.hasClient()) {
    if (!telnetClient || !telnetClient.connected()) {
      if (telnetClient) telnetClient.stop();
      telnetClient = telnetServer.available();
      // Clear the screen on connect (ANSI Clear Screen)
      telnetClient.print("\033[2J\033[H");
      telnetClient.println(String(C_GREEN) + "=== OTA DEBUG CONNECTION ESTABLISHED ===" + C_RESET);
    } else {
      telnetServer.available().stop();
    }
  }
}

// Write a colored state label into buf (no heap allocation, unlike a String return).
void fmtState(char* buf, size_t n, bool state, const char* tTrue, const char* tFalse) {
  snprintf(buf, n, "%s%s%s", state ? C_GREEN : C_RED, state ? tTrue : tFalse, C_RESET);
}

// ==========================================
// SETUP
// ==========================================
void setup() {
  Serial.begin(115200);

  pinMode(HEATER_1_PIN, OUTPUT);
  pinMode(HEATER_2_PIN, OUTPUT);
  pinMode(JET_PIN, OUTPUT);
  pinMode(PUMP_PIN, OUTPUT);

  pinMode(TEMP_1_PIN, INPUT);
  pinMode(TEMP_2_PIN, INPUT);
  pinMode(FLOW_1_PIN, INPUT);
  pinMode(FLOW_2_PIN, INPUT);
  pinMode(TEMP_FUSE_PIN, INPUT);

  // --- WIFIMANAGER ---
  loadConfig();

  WiFiManager wm;
  wm.setSaveConfigCallback(saveConfigCallback);

  pinMode(0, INPUT_PULLUP); // GPIO 0 = ESP32 BOOT button
  if (digitalRead(0) == LOW) {
    Serial.println("BOOT button held: erasing WiFi settings!");
    wm.resetSettings();
  }

  WiFiManagerParameter custom_mqtt_server("server", "MQTT Server", mqttServer, 40);
  WiFiManagerParameter custom_mqtt_port("port", "MQTT Port", mqttPortStr, 6);
  WiFiManagerParameter custom_mqtt_user("user", "MQTT User", mqttUser, 32);
  WiFiManagerParameter custom_mqtt_pass("pass", "MQTT Password", mqttPass, 32, "type='password'");
  WiFiManagerParameter custom_ota_pass("otapass", "OTA Password", otaPass, 32, "type='password'");

  wm.addParameter(&custom_mqtt_server);
  wm.addParameter(&custom_mqtt_port);
  wm.addParameter(&custom_mqtt_user);
  wm.addParameter(&custom_mqtt_pass);
  wm.addParameter(&custom_ota_pass);

  wm.setConfigPortalTimeout(180);

  Serial.println("Attempting WiFi connection...");

  if (!wm.autoConnect("Spa-Intex-Config")) {
    Serial.println("WiFi connection failed -> Offline mode enabled");
    offline_mode = true;
  } else {
    Serial.println("WiFi connected!");
    offline_mode = false;

    strcpy(mqttServer, custom_mqtt_server.getValue());
    strcpy(mqttPortStr, custom_mqtt_port.getValue());
    strcpy(mqttUser, custom_mqtt_user.getValue());
    strcpy(mqttPass, custom_mqtt_pass.getValue());
    strcpy(otaPass, custom_ota_pass.getValue());
    mqttPort = atoi(mqttPortStr);

    if (shouldSaveConfig) {
      saveConfig();
      Serial.println("New MQTT configuration saved.");
    }
  }

  if(!offline_mode) {
    telnetServer.begin();
    if(mqtt_enable) connect_mqtt();
    if(ota_enable) activateOTA();
  }

  test_relay();

  esp_task_wdt_config_t wdt_config = {
    .timeout_ms = WDT_TIMEOUT * 1000,
    .idle_core_mask = (1 << portNUM_PROCESSORS) - 1,
    .trigger_panic = true
  };
  esp_task_wdt_init(&wdt_config);
  esp_task_wdt_add(NULL);
  debugPrintln(String(C_GREEN) + "Watchdog enabled successfully!" + C_RESET);
}

// ==========================================
// MAIN LOOP
// ==========================================
void loop() {
  heartbeat = millis();

  handleTelnet();

  if (resetRequested && (heartbeat - resetTimer >= resetDelay)) {
    debugPrintln(String(C_YELLOW) + "Rebooting the ESP32..." + C_RESET);
    delay(500);
    ESP.restart();
  }

  if(ota_enable) {
    ArduinoOTA.handle();
  }

  if(mqtt_enable) {
    if (!MQTTclient.connected() && !offline_mode) {
      static unsigned long lastMqttRetry = 0;
      if (heartbeat - lastMqttRetry > 5000) {
        lastMqttRetry = heartbeat;
        connect_mqtt();
      }
    }
    MQTTclient.loop();
  }

  if (heartbeat - previousSensorRead >= sensor_read_interval) {
    previousSensorRead = heartbeat;
    read_sensors();
  }

  if(mqtt_enable && !offline_mode && MQTTclient.connected()) {
    if (heartbeat - previousHeartbeat >= mqtt_update_interval || request_mqtt_update) {
      previousHeartbeat = heartbeat;
      request_mqtt_update = false;
      update_mqtt_server();
    }
  }

  update_relay_state();

  static unsigned long lastDebugInfo = 0;
  if (heartbeat - lastDebugInfo > 5000) {
    lastDebugInfo = heartbeat;

    unsigned long elapsedSec = (heartbeat - lastHeatingStateChange) / 1000;
    unsigned long elMins = elapsedSec / 60;
    unsigned long elSecs = elapsedSec % 60;

    char line[200];
    char a[48], b[48];

    // Cycle lock state
    char lock[80];
    if (elapsedSec < (minHeatingCycle / 1000)) {
      unsigned long remSec = (minHeatingCycle / 1000) - elapsedSec;
      snprintf(lock, sizeof(lock), "%s%lum %lus remaining%s", C_YELLOW, remSec / 60, remSec % 60, C_RESET);
    } else {
      snprintf(lock, sizeof(lock), "%sUNLOCKED%s", C_GREEN, C_RESET);
    }
    if (isFirstCycle) strncat(lock, " (ignored for 1st cycle)", sizeof(lock) - strlen(lock) - 1);

    // Diagnostic (every branch is a compile-time constant colored literal)
    const char* diag = C_GREEN "Normal operation" C_RESET;
    if(temp_regulation_enabled && !heating_enabled) {
      if(!fuse && !bypass_fuse) diag = C_RED "BLOCKED: Thermal fuse tripped" C_RESET;
      else if((!flow_1 || !flow_2) && !bypass_flow) diag = C_RED "BLOCKED: No water flow" C_RESET;
      else if(current_temp >= max_temp) diag = C_RED "BLOCKED: 39C safety limit" C_RESET;
      else if(current_temp >= (target_temp - hysterisys) && current_temp <= (target_temp + hysterisys)) diag = C_YELLOW "Dead zone (hysteresis)" C_RESET;
      else if(current_temp > target_temp) diag = C_CYAN "Water at target temperature" C_RESET;
      else if(!isFirstCycle && elapsedSec < (minHeatingCycle / 1000)) diag = C_YELLOW "Waiting (anti-short-cycle)" C_RESET;
    }
    else if (temp_regulation_enabled && heating_enabled) {
      diag = C_GREEN "HEATING: Heating normally" C_RESET;
    }

    debugPrintln();
    debugPrintln(C_CYAN "===================================================" C_RESET);
    debugPrintln(C_CYAN "               SPA INTEX - DASHBOARD               " C_RESET);
    debugPrintln(C_CYAN "===================================================" C_RESET);

    snprintf(line, sizeof(line), "  Temperature  : %s%.1f C%s (Target: %s%.1f C%s)", C_YELLOW, current_temp, C_RESET, C_YELLOW, target_temp, C_RESET);
    debugPrintln(line);

    fmtState(a, sizeof(a), temp_regulation_enabled, "ACTIVE", "INACTIVE");
    snprintf(line, sizeof(line), "  Thermostat   : [%s]", a);
    debugPrintln(line);

    fmtState(a, sizeof(a), filtration_enabled, "ACTIVE", "INACTIVE");
    snprintf(line, sizeof(line), "  Filtration   : [%s]", a);
    debugPrintln(line);

    fmtState(a, sizeof(a), jet_enabled, "ON", "OFF");
    snprintf(line, sizeof(line), "  Bubbles (Jet): [%s]", a);
    debugPrintln(line);

    fmtState(a, sizeof(a), heating_enabled, "HEATING", "OFF");
    snprintf(line, sizeof(line), "  Heating      : [%s]", a);
    debugPrintln(line);

    fmtState(a, sizeof(a), flow_1, "DETECTED", "NO FLOW");
    fmtState(b, sizeof(b), flow_2, "DETECTED", "NO FLOW");
    snprintf(line, sizeof(line), "  Water Sensor : F1 [%s]  |  F2 [%s]", a, b);
    debugPrintln(line);

    fmtState(a, sizeof(a), !bypass_fuse, "ACTIVE", "BYPASSED");
    fmtState(b, sizeof(b), !bypass_flow, "ACTIVE", "BYPASSED");
    snprintf(line, sizeof(line), "  Interlocks   : Fuse [%s]  |  Flow [%s]", a, b);
    debugPrintln(line);

    debugPrintln(C_CYAN "---------------------------------------------------" C_RESET);

    snprintf(line, sizeof(line), "  Timer        : %lum %lus elapsed", elMins, elSecs);
    debugPrintln(line);

    snprintf(line, sizeof(line), "  Cycle lock   : %s", lock);
    debugPrintln(line);

    snprintf(line, sizeof(line), "  Diagnostic   : %s", diag);
    debugPrintln(line);

    debugPrintln(C_CYAN "===================================================" C_RESET);
  }

  esp_task_wdt_reset();
}

// ==========================================
// MQTT AUTO-DISCOVERY (HOME ASSISTANT)
// ==========================================
void publishMQTTDiscovery() {
  debugPrintln(String(C_CYAN) + "Sending MQTT auto-discovery..." + C_RESET);

  String deviceStr = "\"dev\":{\"ids\":[\"spa_intex_esp32\"],\"name\":\"Spa Intex\",\"mdl\":\"DIY ESP32\",\"mf\":\"Custom\"}";

  // 1. Temperature sensor
  String topicTemp = "homeassistant/sensor/spa_intex/temperature/config";
  String payloadTemp = "{\"name\":\"Spa Temperature\",\"stat_t\":\"spa_intex/info\",\"val_tpl\":\"{{ value_json.temp_2 }}\",\"unit_of_meas\":\"°C\",\"dev_cla\":\"temperature\",\"stat_cla\":\"measurement\",\"uniq_id\":\"spa_temp\"," + deviceStr + "}";
  MQTTclient.publish(topicTemp.c_str(), payloadTemp.c_str(), true);

  // 2. Thermostat as a single climate entity (replaces the old number + switch below).
  //    Reuses the existing spa_intex/target and spa_intex/thermostat command topics.
  String topicClimate = "homeassistant/climate/spa_intex/thermostat/config";
  String payloadClimate = "{\"name\":\"Spa\",\"modes\":[\"off\",\"heat\"],\"mode_cmd_t\":\"spa_intex/thermostat\",\"mode_stat_t\":\"spa_intex/info\",\"mode_stat_tpl\":\"{{ 'heat' if value_json.thermostat else 'off' }}\",\"temp_cmd_t\":\"spa_intex/target\",\"temp_stat_t\":\"spa_intex/info\",\"temp_stat_tpl\":\"{{ value_json.target }}\",\"curr_temp_t\":\"spa_intex/info\",\"curr_temp_tpl\":\"{{ value_json.temp_2 }}\",\"act_t\":\"spa_intex/info\",\"act_tpl\":\"{{ 'heating' if value_json.heater else ('idle' if value_json.thermostat else 'off') }}\",\"min_temp\":20,\"max_temp\":39,\"temp_step\":1,\"temp_unit\":\"C\",\"uniq_id\":\"spa_climate\"," + deviceStr + "}";
  MQTTclient.publish(topicClimate.c_str(), payloadClimate.c_str(), true);

  // 3. Remove the legacy number + switch entities (clear their retained discovery).
  MQTTclient.publish("homeassistant/number/spa_intex/target/config", "", true);
  MQTTclient.publish("homeassistant/switch/spa_intex/thermostat/config", "", true);

  // 4. Filtration switch
  String topicFilt = "homeassistant/switch/spa_intex/filtration/config";
  String payloadFilt = "{\"name\":\"Spa Filtration\",\"stat_t\":\"spa_intex/info\",\"val_tpl\":\"{{ '1' if value_json.filtration else '0' }}\",\"cmd_t\":\"spa_intex/filtration\",\"pl_on\":\"1\",\"pl_off\":\"0\",\"uniq_id\":\"spa_filt\"," + deviceStr + "}";
  MQTTclient.publish(topicFilt.c_str(), payloadFilt.c_str(), true);

  // 5. Bubbles (Jet) switch
  String topicJet = "homeassistant/switch/spa_intex/jet/config";
  String payloadJet = "{\"name\":\"Spa Bubbles\",\"stat_t\":\"spa_intex/info\",\"val_tpl\":\"{{ '1' if value_json.jet else '0' }}\",\"cmd_t\":\"spa_intex/jet\",\"pl_on\":\"1\",\"pl_off\":\"0\",\"uniq_id\":\"spa_jet\"," + deviceStr + "}";
  MQTTclient.publish(topicJet.c_str(), payloadJet.c_str(), true);

  // 6. Water-flow interlock bypass (configuration category)
  String topicBpFlow = "homeassistant/switch/spa_intex/bypass_flow/config";
  String payloadBpFlow = "{\"name\":\"Spa Flow Bypass\",\"stat_t\":\"spa_intex/info\",\"val_tpl\":\"{{ '1' if value_json.bypass_flow else '0' }}\",\"cmd_t\":\"spa_intex/bypass_flow\",\"pl_on\":\"1\",\"pl_off\":\"0\",\"ent_cat\":\"config\",\"uniq_id\":\"spa_bypass_flow\"," + deviceStr + "}";
  MQTTclient.publish(topicBpFlow.c_str(), payloadBpFlow.c_str(), true);

  // 7. Thermal-fuse interlock bypass (configuration category)
  String topicBpFuse = "homeassistant/switch/spa_intex/bypass_fuse/config";
  String payloadBpFuse = "{\"name\":\"Spa Fuse Bypass\",\"stat_t\":\"spa_intex/info\",\"val_tpl\":\"{{ '1' if value_json.bypass_fuse else '0' }}\",\"cmd_t\":\"spa_intex/bypass_fuse\",\"pl_on\":\"1\",\"pl_off\":\"0\",\"ent_cat\":\"config\",\"uniq_id\":\"spa_bypass_fuse\"," + deviceStr + "}";
  MQTTclient.publish(topicBpFuse.c_str(), payloadBpFuse.c_str(), true);

  debugPrintln(String(C_GREEN) + "MQTT auto-discovery sent successfully!" + C_RESET);
}

// ==========================================
// MQTT LOGIC
// ==========================================
void connect_mqtt() {
  if (strlen(mqttServer) == 0) return;

  MQTTclient.setServer(mqttServer, mqttPort);
  MQTTclient.setCallback(mqttcallback);

  MQTTclient.setBufferSize(2048); // headroom for the larger climate discovery payload
  // Bound the blocking connect() (CONNACK wait) below the 8s watchdog so an
  // unreachable broker cannot stall loop() long enough to trigger a reboot.
  MQTTclient.setSocketTimeout(4);

  if (!MQTTclient.connected()) {
    debugPrint("Attempting MQTT connection: ");
    debugPrintln(mqttServer);

    if (MQTTclient.connect("IntexSpaClient", mqttUser, mqttPass)) {
      debugPrintln(String(C_GREEN) + "Connected to MQTT broker" + C_RESET);

      publishMQTTDiscovery();

      MQTTclient.subscribe(mqttTopicJet);
      MQTTclient.subscribe(mqttTopicFiltration);
      MQTTclient.subscribe(mqttTopicTarget);
      MQTTclient.subscribe(mqttTopicTempRegulation);
      MQTTclient.subscribe(mqttTopicReset);
      MQTTclient.subscribe(mqttTopicBypassFlow);
      MQTTclient.subscribe(mqttTopicBypassFuse);
    } else {
      debugPrint(String(C_RED) + "Error: MQTT state code = " + C_RESET);
      debugPrintln(MQTTclient.state());
    }
  }
}

void mqttcallback(char* topic, byte* payload, unsigned int length) {
  char msgBuffer[length + 1];
  memcpy(msgBuffer, payload, length);
  msgBuffer[length] = '\0';
  String message = String(msgBuffer);

  debugPrint(String(C_MAGENTA) + "MQTT -> [" + topic + "] : " + C_RESET);
  debugPrintln(message);

  if(strcmp(topic, mqttTopicTarget) == 0) {
    target_temp = message.toFloat();
    if(target_temp > max_temp) target_temp = max_temp;
    request_mqtt_update = true;
  }
  else if(strcmp(topic, mqttTopicJet) == 0) {
    jet_enabled = (message == "1");
    request_mqtt_update = true;
  }
  else if(strcmp(topic, mqttTopicFiltration) == 0) {
    filtration_enabled = (message == "1");
    request_mqtt_update = true;
  }
  else if(strcmp(topic, mqttTopicReset) == 0) {
    if(message == "1") {
      debugPrintln(String(C_YELLOW) + "Reboot requested via MQTT. Executing in 10 seconds..." + C_RESET);
      resetRequested = true;
      resetTimer = millis();
    }
  }
  else if(strcmp(topic, mqttTopicTempRegulation) == 0) {
    // Accepts "1"/"0" (switch) or "heat"/"off" (HA climate mode).
    if(message == "1" || message == "heat") {
      temp_regulation_enabled = true;
      filtration_enabled = true;
    } else {
      temp_regulation_enabled = false;
    }
    request_mqtt_update = true;
  }
  else if(strcmp(topic, mqttTopicBypassFlow) == 0) {
    bypass_flow = (message == "1");
    if(bypass_flow) debugPrintln(String(C_RED) + "WARNING: WATER FLOW interlock bypassed!" + C_RESET);
    request_mqtt_update = true;
  }
  else if(strcmp(topic, mqttTopicBypassFuse) == 0) {
    bypass_fuse = (message == "1");
    if(bypass_fuse) debugPrintln(String(C_RED) + "WARNING: THERMAL FUSE interlock bypassed!" + C_RESET);
    request_mqtt_update = true;
  }
}

// ==========================================
// HELPER METHODS
// ==========================================
void test_relay() {
  debugPrintln("Relay self-test...");
  digitalWrite(HEATER_1_PIN, HIGH); delay(200); digitalWrite(HEATER_1_PIN, LOW); delay(200);
  digitalWrite(HEATER_2_PIN, HIGH); delay(200); digitalWrite(HEATER_2_PIN, LOW); delay(200);
  digitalWrite(JET_PIN, HIGH);      delay(200); digitalWrite(JET_PIN, LOW);      delay(200);
  digitalWrite(PUMP_PIN, HIGH);     delay(200); digitalWrite(PUMP_PIN, LOW);     delay(200);
  debugPrintln(String(C_GREEN) + "Self-test finished." + C_RESET);
}
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

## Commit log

2019-05-02 Updating the electrical drawing with the last version of the board.
2019-05-02 Adding eagle files
    [intex_spa_V4.brd, intex_spa_V4.sch]
2026-06-21 Update README to match current firmware and add CLAUDE.md
    README now documents the WiFiManager captive portal, MQTT/Home Assistant
    auto-discovery control flow, and Telnet debug, replacing the stale aREST
    HTTP API and hardcoded-credentials instructions.
2026-06-21 Restore flow-sensor interlock so heating requires water flow
    read_sensors() hardcoded flow_1/flow_2 to true, which disabled the
    "no flow -> no heat" safety cutoff in must_heat()/activate_heating().
    Read the real digital inputs instead, add the missing FLOW_2_PIN pinMode,
    and expose the active level as FLOW_ACTIVE_LEVEL (verify against the board).
    [intex_spa_manager.ino]
2026-06-21 Enforce thermal-fuse interlock as a heating cutoff
    The temperature fuse was read into `fuse` but never acted on. Treat it as
    a hard interlock: heating is blocked in must_heat(), activate_heating() and
    the MQTT force path unless the fuse reads intact. `fuse` now means
    "intact/OK"; FUSE_OK_LEVEL sets the polarity (verify against the board).
    A disconnected fuse line reads "tripped" and blocks heating (fail-safe).
    [intex_spa_manager.ino]
2026-06-21 Stagger heater startup and bar jet + heater 2 running together
    Implements the original board's current-limiting rules: heater 2 now
    energizes only ~20s after heater 1 (heaterStageDelay) and never while the
    jet/air pump is on, both enforced non-blockingly in activate_heating().
    The MQTT force path amorces heater 1 only and defers heater 2 to the same
    staged logic, dropping its blocking delay(500).
2026-06-21 Protect OTA updates with a configurable password
    ArduinoOTA.begin() was called with no password, letting anyone on the LAN
    flash the mains controller. Add an OTA password configured through the
    WiFiManager captive portal and persisted in Preferences (no secret in the
    repo), set it via setPassword(), and warn loudly when left empty.
2026-06-21 Document OTA password and safety interlocks in README
    Add the OTA password portal field and warning, a new "Safety interlocks
    and current limiting" section (flow + thermal-fuse interlocks, heater
    stagger, jet/heater-2 exclusion, FLOW_ACTIVE_LEVEL/FUSE_OK_LEVEL polarity
    and fail-safe behaviour), and fix the stale info payload example.
2026-06-21 Relabel flow sensors in dashboard and move sketch into IDE folder
    The Telnet/serial dashboard still showed flow as "FORCÉ (1)", a leftover
    from when flow_1/flow_2 were stubbed true. Now that the real inputs are
    read, show "DÉTECTÉ" / "PAS DE DÉBIT" instead. Also relocate the sketch
    into an intex_spa_manager/ folder so the Arduino IDE can open it.
2026-06-21 Add MQTT bypass for flow-sensor and thermal-fuse interlocks
    A blown fuse or faulty flow sensor previously blocked all heating with no
    override. Add two non-persistent MQTT switches (spa_intex/bypass_flow,
    spa_intex/bypass_fuse) that relax the corresponding interlock in must_heat(),
    activate_heating() and the heater-force path. Both default OFF and reset on
    every boot, are published in the info payload, exposed as Home Assistant
    config-category switches, and shown on the serial/Telnet dashboard with a red
    warning when engaged. The 39C ceiling stays as a backstop. README updated.
    [intex_spa_manager.ino]
2026-06-21 Document bypass topics and refresh safety notes in CLAUDE.md
    Add the spa_intex/bypass_flow / bypass_fuse topics and the five-place
    command-topic pattern, fold the fuse interlock and bypass overrides into the
    heating-logic section, note the inrush rules, and correct the stale
    "flow sensors stubbed to true" description (now reads real inputs).
2026-06-21 Remove dead spa_intex/heater force command
    The heater-force MQTT command was overridden by must_heat() on the next loop
    unless the thermostat was already on, making it non-functional. Remove its
    topic declaration, subscription and callback branch, and drop it from the
    README command list. The read-only "heater" state field in the info payload
    (heating_enabled) is kept. Heating is controlled via spa_intex/thermostat.
2026-06-21 Gate heating on both flow sensors (flow_1 AND flow_2)
    Per the original board, both flow switches must detect flow for heating. Add
    flow_2 to the interlock in must_heat() and activate_heating() (AND of both
    sensors), with bypass_flow still overriding the whole flow check. Dashboard
    "No water flow" diagnostic now triggers if either sensor reads no flow.
2026-06-21 Bound MQTT connect below the watchdog to avoid reboot loops
    PubSubClient.connect() blocks waiting for CONNACK up to its socket timeout
    (default 15s), which combined with the TCP connect can exceed the 8s task
    watchdog when the broker is unreachable, causing reboot loops. Set
    setSocketTimeout(4) so the worst case (~3s TCP + 4s CONNACK) stays under the
    WDT; the existing 5s retry throttle in loop() is unchanged.
    [intex_spa_manager.ino]
2026-06-21 Align HA target setpoint max with firmware clamp (39C)
    The Home Assistant discovery advertised max 40 while the firmware clamps the
    target to max_temp (39C), so the UI offered a degree the board silently
    rejected. Set the discovery number max to 39.
2026-06-21 Build the dashboard without String to avoid heap churn
    The 5s serial/Telnet dashboard rebuilt dozens of temporary Arduino Strings
    every cycle, a long-run fragmentation risk. Render it with snprintf into stack
    char buffers, replace the String-returning formatState() with a buffer-filling
    fmtState(), and use the C_* ANSI macros as compile-time literal concatenations.
    No heap allocation per cycle; output is unchanged.
    [intex_spa_manager.ino]
2026-06-21 Document actual temp sensor wiring (temp_2 = intake)
    On the real hardware temp_2 (TEMP_2_PIN) is the pump-intake sensor reading
    true spa water and is the correct regulation sensor; temp_1 is the heater
    exhaust. This is the opposite of the README section-1 numbering (which
    describes the original Intex board). Note it in CLAUDE.md so current_temp =
    temp_2 is not mistakenly "corrected" to temp_1.
2026-06-22 Expose thermostat as a Home Assistant climate entity
    Replace the separate Spa Thermostat switch and Spa Target number with a single
    HA climate entity (current temp = temp_2, 20-39C target, off/heat mode, and a
    heating/idle action badge). It reuses the existing spa_intex/target and
    spa_intex/thermostat command topics and the spa_intex/info state, so no new
    state plumbing. The thermostat callback now accepts "heat"/"off" in addition to
    "1"/"0". The legacy number/switch discovery configs are cleared with an empty
    retained payload so HA drops them, and the MQTT buffer is raised to 2048 for the
    larger climate payload. README and CLAUDE.md updated.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
    [intex_spa_manager.ino]

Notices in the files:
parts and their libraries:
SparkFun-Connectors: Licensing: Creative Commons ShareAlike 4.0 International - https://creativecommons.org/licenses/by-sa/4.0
